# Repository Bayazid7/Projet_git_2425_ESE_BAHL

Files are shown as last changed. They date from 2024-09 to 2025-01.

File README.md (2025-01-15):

# Projet_git_2425_ESE
Projet_2024/2025
## Membres du groupes
Bayazid BELKHIR
<br>
Hedia WERHENI
<br>
Hugo DEVAUX
<br>
Aliou LY

## Introduction

Ce projet a pour objectif de développer un **robot autonome** utilisant un **microcontrôleur STM32** pour la gestion de son comportement, tout en appliquant des principes de noyaux **temps réel** pour contrôler la communication entre ses composants matériels et logiciels. Ce robot sera capable de fonctionner en deux modes :
- **Mode Chat** :
- **Mode Souris** :

Le robot est alimenté par une batterie de 7.2V et comprend des composants essentiels pour son fonctionnement tels que des moteurs, un accéléromètre, et un LIDAR.

---

## Objectifs du projet

Les principaux objectifs de ce projet sont les suivants :
1. **Conception du système à microcontrôleur STM32** : Intégrer un microcontrôleur  pour gérer le comportement du robot.
2. **Implémentation d'un noyau temps réel** : Utiliser un noyau temps réel pour garantir une gestion efficace des tâches .
3. **Contrôle des moteurs avec PWM** : Piloter deux moteurs à l'aide de drivers PWM pour contrôler la vitesse et la direction.
4. **Détection des chocs avec l'accéléromètre ADXL343** : Détecter les collisions avec d'autres robots pour ajuster les actions du robot.
5. **Détection des autres robots avec LIDAR YDLIDAR X4** : Utiliser un LIDAR pour permettre au robot de connaître la position des autres robots.


---

## Matériel utilisé

### 1. **Microcontrôleur STM32**

Le projet repose sur un **STM32** qui gère l'ensemble du système.La programmation du STM32 se fait par un SW

- **Modèle utilisé** : STM32G431CBU6
- **Fonction principale** : Gestion des moteurs, communication avec l'accéléromètre et le LIDAR, traitement des données en temps réel.
- **Peripherals** : PWM pour le contrôle des moteurs, interfaces I2C pour l'accéléromètre et UARTpour  le LIDAR et la communication avec le PC.
  image_stm32

### 2. **Alimentation et régulation de tension**

Le robot est alimenté par une batterie **NIMH 7.2V 1.3Ah**. Cette tension est ensuite convertie en différentes tensions nécessaires au bon fonctionnement des différents composants :
- **Convertisseur 3.3V BU33SD5WG-TR** pour alimenter le STM32, l'accéléromètre, et les capteurs de position des moteurs.
- **Convertisseur 5V  MP1475S** pour alimenter le LIDAR.


---

### 3. **Drivers de moteurs PWM**

Le robot est équipé de **deux moteurs DC**, chacun étant contrôlé par un driver PWM. Chaque driver reçoit des signaux PWM du STM32 pour réguler la vitesse et la direction des moteurs.

- **Modèle des drivers** : ZXBM5210-SP-13
- **Fonction principale** : Piloter les moteurs en avant ou en arrière grâce à des signaux PWM.
- **Commandes PWM** : Les signaux PWM (Forward et Reverse) contrôlent la direction des moteurs. La vitesse est ajustée en modifiant le rapport cyclique du PWM.


### 4. **Accéléromètre ADXL343**

L'accéléromètre **ADXL343** est utilisé pour détecter les chocs entre les robots. Il mesure l'accélération dans les trois axes et peut détecter des variations rapides, comme celles d'une collision.

- **Communication** : Le module utilise le protocole **I2C** pour envoyer les données d'accélération au STM32.
- **Fonction principale** : Détecter les impacts ou les vibrations et permettre une réaction rapide du robot (comme changer de direction ou ajuster son comportement).


### 5. **LIDAR YDLIDAR X2**

Le **LIDAR YDLIDAR X4** est utilisé pour scanner l'environnement autour du robot et déterminer la position des autres robots et des obstacles. 
- **Type de capteur** : **LIDAR à balayage laser**.
- **Portée** : Jusqu'à 12 mètres.
- **Communication** : **UART**  pour transmettre les données de mesure.
- **Protocole**  : Utilise une communication série avec un format de trame spécifique (en-tête 0x55AA).
- **Résolution** : Distance : 0.25 mm (valeur brute divisée par 4) et Angle : 1/64° (0.015625°)

---
# Schema de cablage



## Software

### **Drivers de Moustache**
### **1. Fichier `Moustache.c`**-contient l'implémentation du pilote pour gérer les interruptions et les tâches liées à un système utilisant des capteurs "moustaches" pour détecter des bords.
**Principales fonctions et variables :
1. **Variables principales :**
   - `cb_out1_task_handle` et `cb_out2_task_handle` : Des handles pour les tâches FreeRTOS associées aux deux GPIO.
   - `exclusive_task` : Variable pour enregistrer quelle tâche est en cours d'exécution, afin d'éviter que plusieurs tâches ne soient actives simultanément ( On a remarqué que lorsque l'une des deux moustaches détecte le bord, la deuxième va également interrompre après un petit moment, et cela est dû à la conception du robot ). 
     - `0`: Aucune tâche active.
     - `1`: La tâche `CB_OUT1_Task` est active.
     - `2`: La tâche `CB_OUT2_Task` est active.
   - `robot` : Variable globale externe, représentant l'état d'un robot. Elle est utilisée dans la fonction `Bord`.

2. **Initialisation (`Moustache_Init`):**
   - Création de deux tâches FreeRTOS :
     - `CB_OUT1_Task` pour gérer les événements associés au GPIO `CB_OUT1_Pin`.
     - `CB_OUT2_Task` pour gérer les événements associés au GPIO `CB_OUT2_Pin`.

3. **Gestion des interruptions (`Moustache_HandleInterrupt`):**
   - Cette fonction est appelée lorsqu'une interruption GPIO est détectée.
   - Vérifie si une tâche peut être exécutée (selon la valeur de `exclusive_task`).
   - Envoie une notification à la tâche correspondante (`cb_out1_task_handle` ou `cb_out2_task_handle`) en utilisant `xTaskNotifyFromISR`.

4. **Fonction `Bord` :**
   - Gère le comportement du robot en fonction de sa direction (`robot.direction`).
     - `'A'`: Le robot recule.
     - `'R'`: Le robot avance.
   - Cette fonction est appelée par les tâches pour ajuster le mouvement du robot.

5. **Tâches `CB_OUT1_Task` et `CB_OUT2_Task` :**
   - Chaque tâche attend une notification via `xTaskNotifyWait`.
   - Lorsqu'une notification est reçue :
     - Elle effectue une action définie (appel de `Bord`).
     - Réinitialise `exclusive_task` à 0 pour permettre d'autres interruptions.

#### **2. Fichier `Moustache.h`**

Ce fichier est l'en-tête associé, qui déclare les prototypes des fonctions et les dépendances nécessaires.

#### **Principales fonctionnalités :**

1. **Inclusion de bibliothèques nécessaires :**
   - `stm32g4xx_hal.h` : Bibliothèque HAL pour la famille STM32G4.
   - `gpio.h` : Bibliothèque pour gérer les GPIO.

2. **Prototypes de fonctions :**
   - `Moustache_Init(void)` : Initialisation du pilote et des tâches.
   - `Moustache_HandleInterrupt(uint16_t GPIO_Pin)` : Gestion des interruptions GPIO.

___
### **Drivers de Moteur**

### 1.Fichier 'MoteurPWM.c' 

1. **La fonction Moteur_init:** 

Est responsable de l'initialisation d'un moteur en configurant ses paramètres de base. Elle prend en entrée un pointeur vers la structure du moteur, le timer PWM et le canal associé, initialisant la direction à l'arrêt et la vitesse à zéro.

2. **Moteur_setSpeed:**
gère la vitesse du moteur avec une conversion d'échelle, transformant une vitesse d'entrée (±290) en valeur PWM (0-8500) et configurant la direction appropriée.

3. **Moteur_setDirection:**

contrôle la direction du moteur en gérant les signaux PWM complémentaires elle peut faire avancer, reculer ou arrêter le moteur en activant ou désactivant les canaux PWM appropriés.

4. **Moteur_start, Moteur_stop et Moteur_recule:**

sont des fonctions d'aide qui simplifient le contrôle du moteur en appelant Moteur_setDirection avec les paramètres appropriés.

Du côté du robot, Robot_Start initialise le mouvement en avant avec des vitesses asymétriques (120 pour la droite, 80 pour la gauche), tandis que Robot_Stop arrête les deux moteurs.Robot_Recule fait reculer le robot avec les mêmes vitesses que l'avance mais en négatif.

## 2.Fichier 'MoteurPWM.h' 

c'est un fichier d’en-tête conçu pour gérer le contrôle des moteurs d’un robot. Il définit deux structures principales :

1. **Moteur_HandleTypeDef :** utilisée pour représenter un moteur individuel, incluant ses paramètres essentiels comme le timer PWM associé (pwm_timer), le canal PWM (channel), la direction actuelle (direction) et la vitesse (vitesse).
   
2. **h_Robot :** utilisée pour représenter un robot comprenant deux moteurs (droit et gauche) et des paramètres globaux comme la vitesse linéaire, la vitesse angulaire, l’angle (theta) et le mode de fonctionnement.

pour que en peux controlé l'angle de lidar nous allons utulisé La fonction : 
xTaskCreate(robotAngle, "Init Task", 256, NULL, 2, &setangleTaskHandle)  sert à créer une tâche dans un système RTOS. Cette tâche exécute la fonction robotAngle telque: 

utilise une pile de 256 mots, et a une priorité de 2. Le nom "Init Task" est utilisé pour identifier la tâche, et le handle setangleTaskHandle permet de la contrôler ultérieurement. Cette commande initialise efficacement la tâche pour qu'elle s'exécute dans le système.

## 4 .Driver ADXL343 (`ADXL343.c`)

## Introduction

Le driver **ADXL343** permet de gérer un accéléromètre **ADXL343** dans un système embarqué en temps réel. Ce capteur mesure l'accélération sur trois axes (X, Y, Z) et est utilisé pour détecter des événements comme les chocs. Ce driver est conçu pour intégrer les fonctionnalités du capteur avec **FreeRTOS**.

### 1. **Initialisation et Configuration du Capteur**

Le driver initialise le **capteur ADXL343** en configurant les registres nécessaires pour le fonctionnement de l'accéléromètre. Cela inclut la configuration de la plage de mesures, des seuils de tapotement, et des interruptions.

- **Initialisation de l'I2C** : La fonction `ADXL343_Init()` initialise la communication I2C avec le capteur, vérifie l'identifiant du dispositif et configure les registres pour la lecture des données d'accélération.
- **Configuration des Interrups** : Le capteur est configuré pour détecter des événements sur les axes X et Y, en activant les interruptions pour ces axes.
- **Configuration du Format des Données** : Le capteur est configuré pour un mode de résolution complète avec une plage de ±16g, ce qui est adapté pour de nombreuses applications.

### 2. **Réception et Traitement des Données**

Une fois l'accéléromètre configuré, le driver permet de récupérer les données d'accélération en temps réel.
- **Traitement des Interruptions** : Le driver utilise des interruptions pour détecter des événements de tapotement (tap) sur les axes X et Y.

### 3. **Gestion des Interruptions**

- **Gestion des Interruptions Tap** : Le capteur est configuré pour activer les interruptions uniquement pour les axes X et Y, en désactivant l'axe **Z** qui peut souvent générer des interruptions indésirables.
  
### 4. **Intégration en Temps Réel** ⏱️

- **Utilisation de FreeRTOS** : Le driver fonctionne avec **FreeRTOS** pour gérer les tâches liées à la lecture des données du capteur et au traitement des événements. Une tâche dédiée `TapDetectedTask` est utilisée pour traiter les événements en temps réel.

## 5. Drivers Ylidar X2 (`lidar_X2_driver.c`)

Le code du dirver implémente la gestion d'un capteur LiDAR YLIDAR X2 dans un système embarqué temps réel. Ci-dessous, les principaux aspects du fonctionnement du LiDAR :
### Initialisation et réception des données
La fonction `lidar_init()` initialise la communication UART avec le LiDAR en mode interruption. La réception des données se fait octet par octet via la fonction `readTrame()`, qui implémente une **machine à états** pour assembler les trames complètes.
### Traitement des données
Une fois une trame complète reçue, `lidar_process()` est appelée pour extraire et traiter les données :
- `lidar_extractDataFromTrame()` décode la structure de la trame.
- `lidar_DataProcessing()` calcule la distance et l'angle pour chaque point mesuré.
- `lidar_calculatingDistance()` et `lidar_calculatingAngle()` effectuent les calculs spécifiques.

### Intégration temps réel
- Utilisation d'interruptions UART pour la réception asynchrone des données.
- Traitement des données dans une tâche FreeRTOS dédiée (`lidarTask`).
- Synchronisation avec d'autres tâches du système pour le contrôle du robot.

### Pistes d'amélioration
- Implémenter la vérification du checksum pour valider l'intégrité des données.
- Optimiser le traitement des données pour réduire la charge CPU.
- Ajouter des filtres pour améliorer la précision des mesures.
- Implémenter une gestion d'erreurs plus robuste.

## Datasheets et sourcing des composants
https://1drv.ms/x/s!AjphXEW6glNckYErezblGW1QHlP9SQ

## Démonstrations du robot en marche:

https://github.com/user-attachments/assets/f6af12cb-7911-474c-adf0-7a1f33a06a41

https://github.com/user-attachments/assets/32c66e7f-6e20-4e83-ad37-8ae89d0b7e4e

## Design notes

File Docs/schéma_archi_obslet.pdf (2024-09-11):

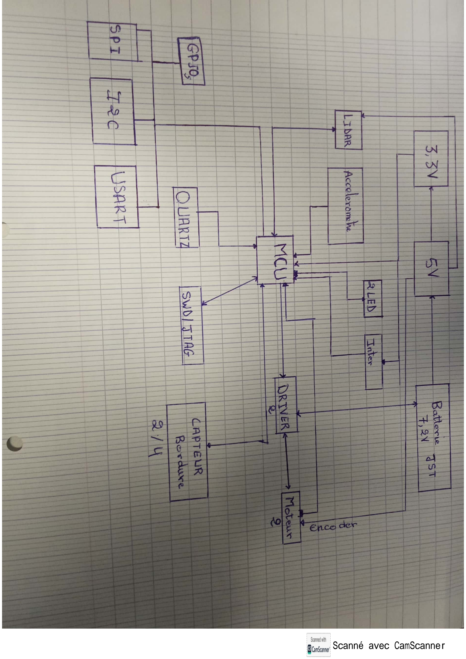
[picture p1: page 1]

Scanné avec CamScanner (https://v3.camscanner.com/user/download)

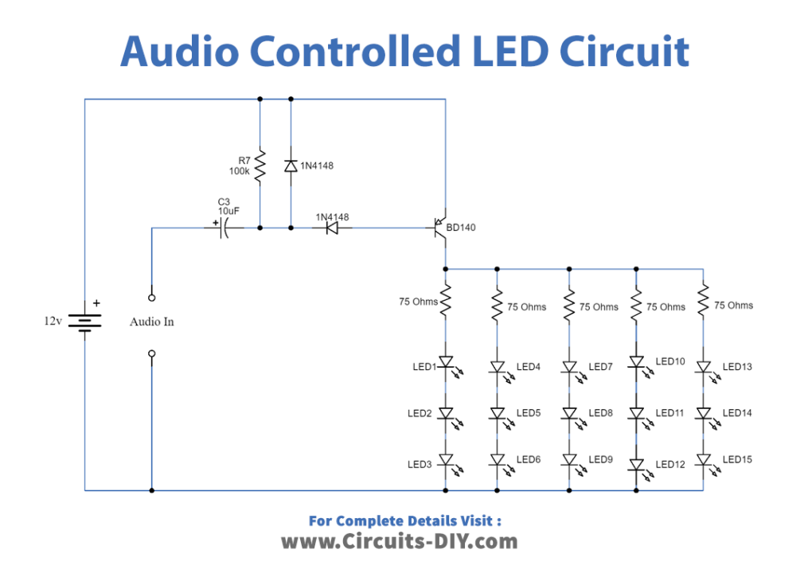
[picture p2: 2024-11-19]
Docs/LIDAR/Audio-Controlled-LED-Circuit-1015x720.png

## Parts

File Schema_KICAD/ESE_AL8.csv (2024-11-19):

Id | Référence | Empreinte | Quantité | Désignation | Fournisseur et réf
1 | R16,R1,R2,R17 | R_0402_1005Metric | 4 | 1k
2 | D3 | LED_0603_1608Metric | 1 | LED_USER2
3 | Y1 | Crystal_SMD_3225-4Pin_3.2x2.5mm | 1 | 16MHz
4 | IC1 | TSOT-23-8 | 1 | MP1475SGJ-P
5 | L1 | IND_052047_WRE | 1 | 4.7u
6 | SW1 | SW_Push_1P1T_NO_6x6mm_H9.5mm | 1 | SW_c/s
7 | C12,C16 | C_0402_1005Metric | 2 | 10p
8 | R10 | R_0402_1005Metric | 1 | 20
9 | U2 | SOT-23-5 | 1 | BUxxSD5
10 | C14,C2,C21,C20,C201,C18,C24,C19,C25,C27,C26,C17 | C_0402_1005Metric | 12 | 100n
11 | D2 | LED_0603_1608Metric | 1 | LED_USER1
12 | C5,C4,C6 | C_0402_1005Metric | 3 | 0.1u
13 | C15,C29,C11,C31,C23,C1,C10 | C_0603_1608Metric | 7 | 1u
14 | R13,R12,R3,R14,R15,R11 | R_0402_1005Metric | 6 | 680
15 | TP6,TP4,TP7,TP8,TP1,TP5,TP3,TP2 | TestPoint_Pad_D1.0mm | 8 | TestPoint
16 | R4,R5 | R_0402_1005Metric | 2 | 100K
17 | D1,D5,D6 | LED_0603_1608Metric | 3 | LED_POWER
18 | C9,C8,C3 | C_0805_2012Metric | 3 | 22u
19 | R6 | R_0603_1608Metric | 1 | 20
20 | C7 | C_0402_1005Metric | 1 | 15p
21 | J4 | JST_XH_S6B-XH-A_1x06_P2.50mm_Horizontal | 1 | Moteur1
22 | J1 | JST_XH_S4B-XH-A_1x04_P2.50mm_Horizontal | 1 | CB1
23 | J5 | JST_XH_S6B-XH-A_1x06_P2.50mm_Horizontal | 1 | Moteur2
24 | U1 | LGA-14_3x5mm_P0.8mm_LayoutBorder1x6y | 1 | ADXL343
25 | C28,C30 | C_0603_1608Metric | 2 | 10u
26 | SW2 | JST_XH_S3B-XH-A_1x03_P2.50mm_Horizontal | 1 | ON/OFF
27 | U4,U5 | Diodes_SO-8EP | 2 | ZXBM5210-SP
28 | R7 | R_0603_1608Metric | 1 | 16k
29 | L2 | C_0402_1005Metric_Pad0.74x0.62mm_HandSolder | 1 | l
30 | J8 | JST_XH_S4B-XH-A_1x04_P2.50mm_Horizontal | 1 | ECRAN
31 | D4 | LED_0603_1608Metric | 1 | LED_USER3
32 | C13 | C_0603_1608Metric | 1 | 4.7u
33 | J2 | JST_XH_S4B-XH-A_1x04_P2.50mm_Horizontal | 1 | CB2
34 | J3 | JST_XH_S8B-XH-A_1x08_P2.50mm_Horizontal | 1 | LIDAR
35 | R8 | R_0603_1608Metric | 1 | 7.68k
36 | J6 | JST_XH_S2B-XH-A_1x02_P2.50mm_Horizontal | 1 | Batterie
37 | J7 | PinHeader_2x07_P1.27mm_Vertical_SMD | 1 | Conn_ST_STDC14
38 | U3 | QFN-48-1EP_7x7mm_P0.5mm_EP5.6x5.6mm_AJ | 1 | STM32G431CBUx
39 | C22 | C_0402_1005Metric | 1 | 10n
40 | R9 | R_0603_1608Metric | 1 | 40.2k

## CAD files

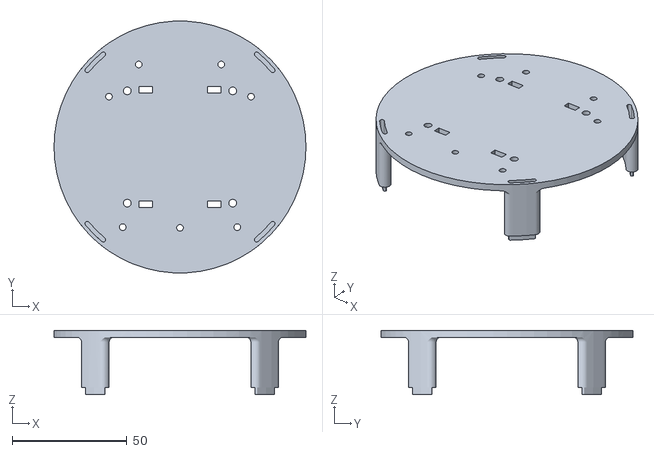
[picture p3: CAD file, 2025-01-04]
Robot_ESE_BAHL/Tower2.stl
110.0 x 109.8 x 28.0

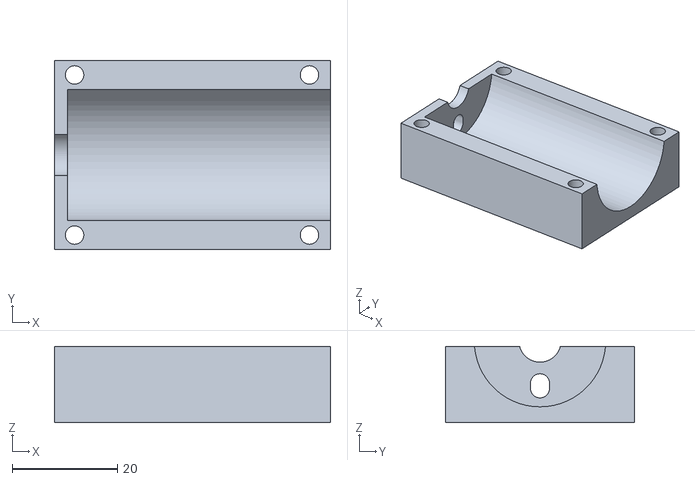
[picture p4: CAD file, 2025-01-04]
Robot_ESE_BAHL/SupportMotor2.stl
52.5 x 36.0 x 14.5

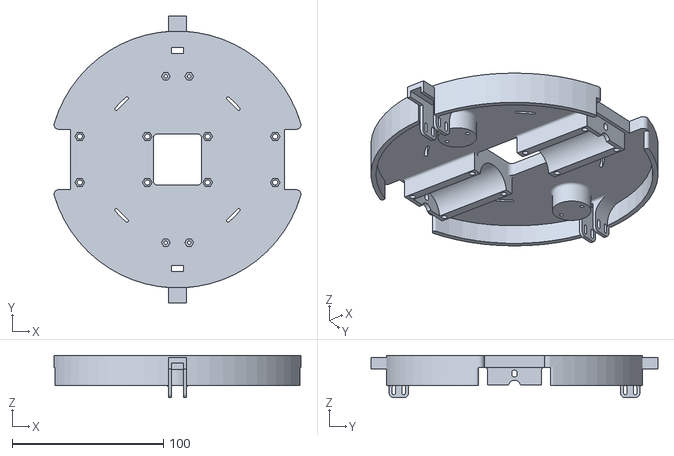
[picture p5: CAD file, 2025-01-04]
Robot_ESE_BAHL/Base (2).stl
163.4 x 190.0 x 28.0

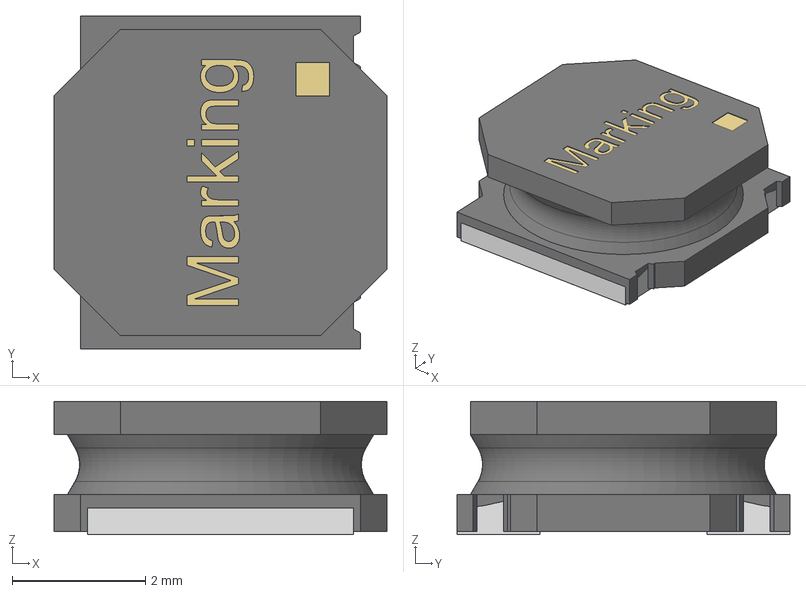
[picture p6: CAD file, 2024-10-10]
Schema_KICAD/FootPrint/Inductance/74404052010_Download_STP_WE-LQS-5020_rev1.stp
5.00 x 5.00 x 2.00 mm
housing
contact x 2
Glue

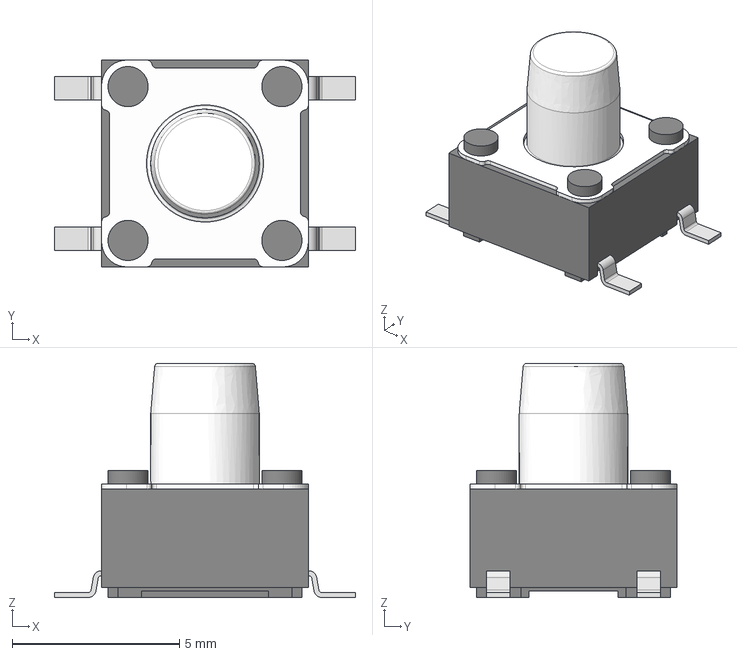
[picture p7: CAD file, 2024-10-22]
Schema_KICAD/Librairie/430182070816_Download_STP_430182070816_rev1.stp
9.00 x 6.20 x 7.00 mm

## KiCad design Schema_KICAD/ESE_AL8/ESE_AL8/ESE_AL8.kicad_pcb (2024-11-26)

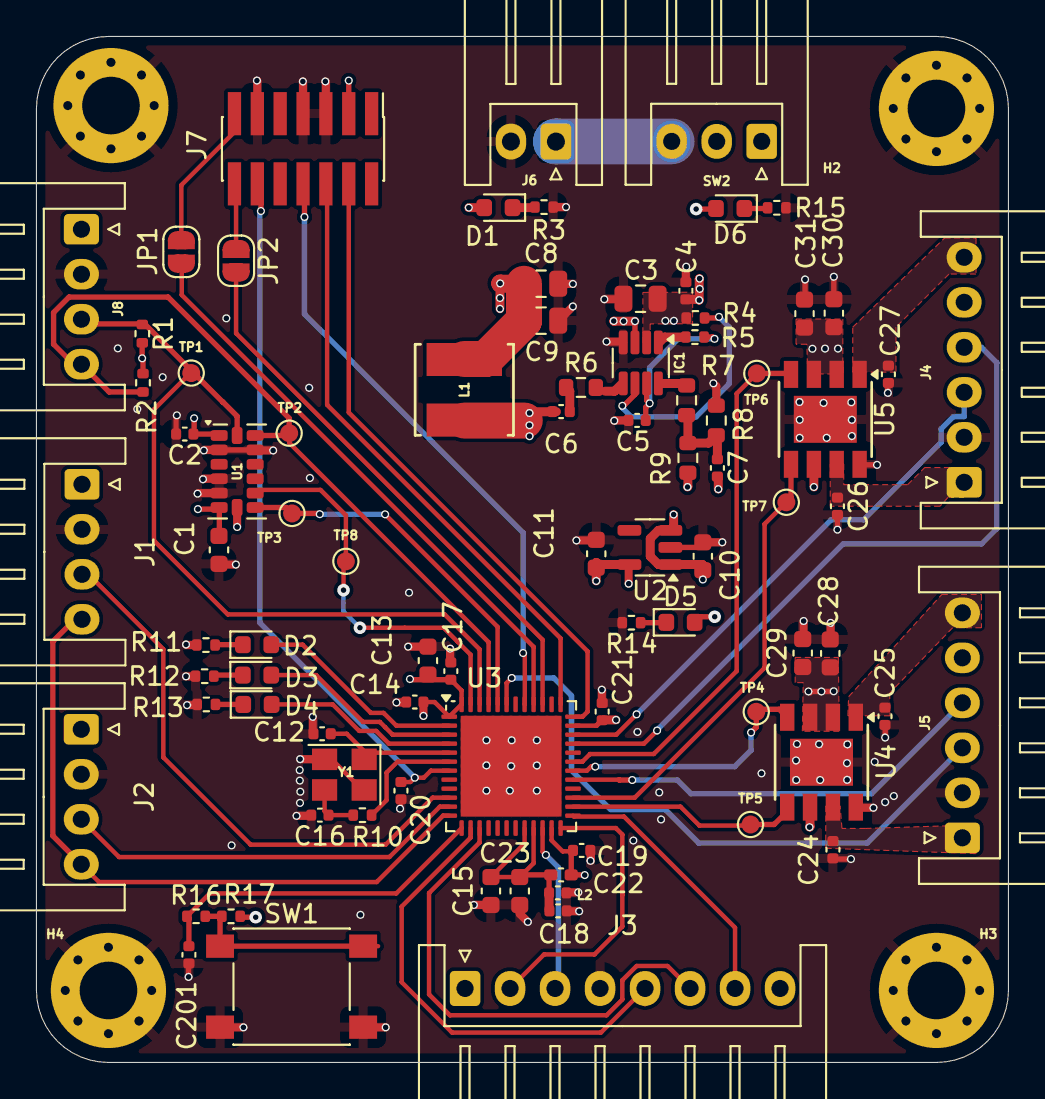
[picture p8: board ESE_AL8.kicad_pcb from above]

Board: 4 copper layers, 54.0 x 57.0 mm, 88 parts (0 on the bottom side), 60 nets.

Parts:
C1, C10, C11, C15, C23, C29, C31: 1u; C_0603_1608Metric
C2, C14, C17, C18, C19, C20, C21, C24, C25, C26, C27, C201: 100n; C_0402_1005Metric
C3, C8, C9: 22u; C_0805_2012Metric
C4, C5, C6: 0.1u; C_0402_1005Metric
C7: 15p; C_0402_1005Metric
C12, C16: 10p; C_0402_1005Metric
C13: 4.7u; C_0603_1608Metric
C22: 10n; C_0402_1005Metric
C28, C30: 10u; C_0603_1608Metric
D1, D5, D6: LED_POWER; LED_0603_1608Metric
D2: LED_USER1; LED_0603_1608Metric
D3: LED_USER2; LED_0603_1608Metric
D4: LED_USER3; LED_0603_1608Metric
H1, H2, H3, H4: MountingHole_Pad; MountingHole_3.2mm_M3_Pad_Via
IC1: MP1475SGJ-P; TSOT-23-8
J1: CB1; JST_XH_S4B-XH-A_1x04_P2.50mm_Horizontal
J2: CB2; JST_XH_S4B-XH-A_1x04_P2.50mm_Horizontal
J3: LIDAR; JST_XH_S8B-XH-A_1x08_P2.50mm_Horizontal
J4: Moteur1; JST_XH_S6B-XH-A_1x06_P2.50mm_Horizontal
J5: Moteur2; JST_XH_S6B-XH-A_1x06_P2.50mm_Horizontal
J6: Batterie; JST_XH_S2B-XH-A_1x02_P2.50mm_Horizontal
J7: Conn_ST_STDC14; PinHeader_2x07_P1.27mm_Vertical_SMD
J8: ECRAN; JST_XH_S4B-XH-A_1x04_P2.50mm_Horizontal
JP1, JP2: SolderJumper_2_Open; SolderJumper-2_P1.3mm_Open_RoundedPad1.0x1.5mm
L1: 4.7u; IND_052047_WRE
L2: l; C_0402_1005Metric_Pad0.74x0.62mm_HandSolder
R1, R2, R16, R17: 1k; R_0402_1005Metric
R3, R11, R12, R13, R14, R15: 680; R_0402_1005Metric
R4, R5: 100K; R_0402_1005Metric
R6: 20; R_0603_1608Metric
R7: 16k; R_0603_1608Metric
R8: 7.68k; R_0603_1608Metric
R9: 40.2k; R_0603_1608Metric
R10: 20; R_0402_1005Metric
SW1: SW_c/s; SW_Push_1P1T_NO_6x6mm_H9.5mm
SW2: ON/OFF; JST_XH_S3B-XH-A_1x03_P2.50mm_Horizontal
TP1, TP2, TP3, TP4, TP5, TP6, TP7, TP8: TestPoint; TestPoint_Pad_D1.0mm
U1: ADXL343; LGA-14_3x5mm_P0.8mm_LayoutBorder1x6y
U2: BUxxSD5; SOT-23-5
U3: STM32G431CBUx; QFN-48-1EP_7x7mm_P0.5mm_EP5.6x5.6mm_AJ
U4, U5: ZXBM5210-SP; Diodes_SO-8EP
Y1: 16MHz; Crystal_SMD_3225-4Pin_3.2x2.5mm

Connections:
+3.3V: C1.1, C2.1, C11.1, C13.1, C14.1, C17.1, C19.1, C21.1, D1.2 (A), J1.1, J2.1, J4.5, J5.5, J7.3 (VCC), J8.1, L2.2, R1.2, R2.2, R17.1, U1.1 (Vdd_I/O), U1.6 (Vs), U1.7 (~CS), U2.5 (VOUT), U3.1 (VBAT), U3.23 (VDD), U3.35 (VDD), U3.48 (VDD)
+3.3VA: C15.1, C18.1, C22.1, C23.1, L2.1, U3.20 (VREF+), U3.21 (VDDA)
+5V: C7.2, C8.1, C9.1, C10.1, D5.2 (A), J3.1, L1.2, R9.2, U2.1 (VIN), U2.3 (STBY)
+7.2V: J6.1, SW2.3 (A)
+BATT: C3.1, C4.1, C28.1, C29.1, C30.2, C31.2, D6.2 (A), IC1.2 (IN), R4.1, SW2.2 (B), U4.2 (VM), U4.3 (VDD), U4.6 (VREF), U5.2 (VM), U5.3 (VDD), U5.6 (VREF)
/Actionneur/FWD1: TP6.1, U3.31 (PA9), U5.4 (FWD)
/Actionneur/FWD2: TP4.1, U3.30 (PA8), U4.4 (FWD)
/Actionneur/MOTEUR1+: C27.2, J4.6, U5.1 (OUT1)
/Actionneur/MOTEUR1-: C26.1, J4.1, U5.7 (OUT2)
/Actionneur/MOTEUR2+: C25.2, J5.6, U4.1 (OUT1)
/Actionneur/MOTEUR2-: C24.1, J5.1, U4.7 (OUT2)
/Actionneur/REV1: TP7.1, U3.27 (PB14), U5.5 (REV)
/Actionneur/REV2: TP5.1, U3.26 (PB13), U4.5 (REV)
/Actionneur/SCL: J8.3, R1.1, TP1.1, U1.14 (SCL/SCLK), U3.46 (PB8)
/Actionneur/SDA: J8.4, R2.1, TP2.1, U1.13 (SDA/SDI/SDIO), U3.45 (PB7)
/Alimentation/bst: IC1.5 (BST), R6.1
/Alimentation/en/sync: IC1.6 (EN/SYNC), R4.2
/Alimentation/fb: IC1.8 (FB), R7.1
/Alimentation/led_power: D1.1 (K), R3.1
/Alimentation/led_power5: D5.1 (K), R14.1
/Alimentation/led_powerBATT: D6.1 (K), R15.1
/Alimentation/pg: IC1.1 (PG), R5.2
/Alimentation/sw: C6.2, IC1.3 (SW), L1.1
/Alimentation/vcc: C5.1, IC1.7 (VCC), R5.1
/SENSORS/CB_IN: J1.4, J2.4, U3.12 (PA4)
/SENSORS/CB_OUT1: J1.3, U3.10 (PA2)
/SENSORS/CB_OUT2: J2.3, U3.11 (PA3)
/SENSORS/CHAT/SOURIS: C201.1, R16.1, U3.13 (PA5)
/SENSORS/DEV_EN_LIDAR: J3.6, U3.15 (PA7)
/SENSORS/INT1_ACCELERO: TP3.1, U1.8 (INT1), U3.44 (PB6)
/SENSORS/INT2_ACCELERO: TP8.1, U1.9 (INT2), U3.47 (PB9)
/SENSORS/M_EN_LIDAR: J3.7, U3.25 (PB12)
/SENSORS/M_SCTR_LIDAR: J3.5, U3.14 (PA6)
/SENSORS/PHASE_A1: J4.3, U3.34 (PA12)
/SENSORS/PHASE_A2: J5.3, U3.43 (PB5)
/SENSORS/PHASE_B1: J4.4, U3.33 (PA11)
/SENSORS/PHASE_B2: J5.4, U3.29 (PC6)
/SENSORS/RX_LIDAR: J3.3, U3.22 (PB10)
/SENSORS/TX_LIDAR: J3.2, U3.24 (PB11)
/STM32/LED1: D2.1 (K), R11.1
/STM32/LED2: D3.1 (K), R12.1
/STM32/LED3: D4.1 (K), R13.1
GND: C1.2, C2.2, C3.2, C4.2, C5.2, C8.2, C9.2, C10.2, C11.2, C12.1, C13.2, C14.2, C15.2, C16.2, C17.2, C18.2, C19.2, C20.2, C21.2, C22.2, C23.2, C24.2, C25.1, C26.2, C27.1, C28.2, C29.2, C30.1, C31.1, C201.2, H1.1, H2.1, H3.1, H4.1, IC1.4 (GND), J1.2, J2.2, J3.4, J4.2, J5.2, J6.2, J7.5 (GND), J7.7 (GND), J7.11 (GNDDetect), J8.2, R3.2, R8.2, R11.2, R12.2, R13.2, R14.2, R15.2, SW1.2, U1.2 (GND), U1.4 (GND), U1.5 (GND), U1.12 (SDO/ADDR), U2.2 (GND), U3.49 (VSS), U4.8 (GND), U4.9 (GND), U5.8 (GND), U5.9 (GND), Y1.2, Y1.4
LD1: D2.2 (A), U3.2 (PC13)
LD2: D3.2 (A), U3.3 (PC14)
LD3: D4.2 (A), U3.4 (PC15)
NRST: C20.1, J7.12 (~RST), U3.7 (PG10)
unnamed: C6.1, R6.2
unnamed: C7.1, R7.2, R8.1, R9.1
unnamed: C16.1, R10.1, Y1.3
unnamed: J7.13 (VCP_RX), JP1.1 (A)
unnamed: J7.14 (VCP_TX), JP2.1 (A)
unnamed: R16.2, R17.2, SW1.1
OSC_IN: C12.2, U3.5 (PF0), Y1.1
OSC_OUT: R10.2, U3.6 (PF1)
RX_SWD: JP1.2 (B), U3.40 (PC11)
SWCLK: J7.6 (JCLK/SWCLK), U3.37 (PA14)
SWDIO: J7.4 (JTMS/SWDIO), U3.36 (PA13)
SWO: J7.8 (JTDO/SWO), U3.41 (PB3)
TX_SWD: JP2.2 (B), U3.39 (PC10)

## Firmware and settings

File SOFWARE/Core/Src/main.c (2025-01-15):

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
/* Includes ------------------------------------------------------------------*/
#include "main.h"
#include "cmsis_os.h"
#include "i2c.h"
#include "tim.h"
#include "usart.h"
#include "gpio.h"

/* USER CODE BEGIN Includes */
#include <stdio.h>
#include "tab.h"
#include "lidar_X2_driver.h"
#include "MoteurPWM.h"
#include "Moustache.h"
#include "ADXL343.h"
/* USER CODE END Includes */


/* USER CODE BEGIN PV */

extern uint8_t sendTab[TABLE_SIZE];
extern uint8_t flagDMA;
extern uint8_t rxByte;
extern float lidar_point[SIZE_POINT] ;
uint8_t flag = 0;

// FreeRTOS Task Handles
TaskHandle_t initTaskHandle = NULL;
TaskHandle_t lidarTaskHandle = NULL;
TaskHandle_t ledBlinkTaskHandle = NULL;
TaskHandle_t h_task_bord = NULL;
static TaskHandle_t TapDetected_task = NULL;
TaskHandle_t modeTaskHandle = NULL;
TaskHandle_t setangleTaskHandle = NULL;

// Robot and peripheral structures
Moteur_HandleTypeDef moteur_droit;
Moteur_HandleTypeDef moteur_gauche;
h_Robot robot;
float angle;
ADXL343_InstanceDef_t ADXL343;
/* USER CODE END PV */

void SystemClock_Config(void);
void MX_FREERTOS_Init(void);
/* USER CODE BEGIN PFP */
int __io_putchar(int chr);
void lidarTask(void *pvParameters);
void ledBlinkTask(void *pvParameters);
void task_angle(void *unused);
void task_Bord(void *unused);
void TapDetected(void *param);
void modeChange(void *param);
void initTask(void *pvParameters);
void robotAngle(void * param);
/* USER CODE END PFP */

/**
 * @brief  The application entry point.
 * @retval int
 */
int main(void)
{

	/* MCU Configuration--------------------------------------------------------*/

	/* Reset of all peripherals, Initializes the Flash interface and the Systick. */
	HAL_Init();

	/* Configure the system clock */
	SystemClock_Config();

	/* Initialize all configured peripherals */
	MX_GPIO_Init();
	MX_TIM1_Init();
	MX_TIM16_Init();
	MX_UART4_Init();
	MX_USART3_UART_Init();
	MX_I2C1_Init();
	MX_TIM2_Init();
	/* USER CODE BEGIN 2 */
	// Peripheral Initialization

	Moteur_init(&moteur_droit, &htim1, TIM_CHANNEL_1);
	Moteur_init(&moteur_gauche, &htim1, TIM_CHANNEL_2);
	Robot_Init(&robot, &moteur_droit, &moteur_gauche);
	Robot_Start(&robot);
	Moustache_Init();
	ADXL343_Init(&ADXL343, &hi2c1);
	HAL_TIM_Base_Start_IT(&htim2) ;
	//Create FreeRTOS tasks
	xTaskCreate(lidarTask, "Lidar Task", 512, NULL, 2, &lidarTaskHandle);
	xTaskCreate(ledBlinkTask, "LED Blink Task", 256, NULL,2, &ledBlinkTaskHandle);
	xTaskCreate(modeChange, "mode", 128, NULL, 5, &modeTaskHandle);
	xTaskCreate(TapDetected, "TapDetected", 128, NULL, 5, &TapDetected_task);
	xTaskCreate(initTask, "Init Task", 256, NULL, 7, &initTaskHandle);
	xTaskCreate(robotAngle, "Init Task", 256, NULL, 2, &setangleTaskHandle) ;

	//
	/* USER CODE END 2 */

	/* Call init function for freertos objects (in cmsis_os2.c) */
	MX_FREERTOS_Init();

	/* Start scheduler */
	osKernelStart();

	/* We should never get here as control is now taken by the scheduler */

	/* Infinite loop */
	/* USER CODE BEGIN WHILE */

	while (1)
	{
		HAL_GPIO_TogglePin(LED1_GPIO_Port, LED1_Pin);
		HAL_GPIO_TogglePin(LED2_GPIO_Port, LED2_Pin);
		HAL_GPIO_TogglePin(LED3_GPIO_Port, LED3_Pin);
		HAL_Delay(500);
		//vTaskDelay(pdMS_TO_TICKS(500));
		//lidar_scan_loop();
		/*if(flag == 1){
			for(int i=0 ; i<POINT_BUFF_SIZE ;i++)
			{
				printf("le point %d a angle %f et diastance %f \r\n",i,lidar.point[i].Angle,lidar.point[i].Distance);
				printf("FSA = %d,LSA=%d , LSN=%d , ind=%d \r\n",lidar.processing.LSA,lidar.processing.LSA,lidar.processing.LSN,lidar.processing.idx);
			}
			flag = 0 ;
		}*/

		/* USER CODE END WHILE */

		/* USER CODE BEGIN 3 */
	}
	/* USER CODE END 3 */
}

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
/* USER CODE BEGIN 4 */

//Lidar Task
void initTask (void *pvParameters)
{
	lidar_init();
	vTaskDelete(NULL);
}

void lidarTask(void *pvParameters)
{
	for(;;)
	{
		if (ulTaskNotifyTake(pdTRUE, portMAX_DELAY) == pdTRUE)
		{
			lidar_process();
		}
	}
}
// Robot orientation task
void robotAngle(void * param)
{ float angle = 0 ;
for(;;)
{

	if (ulTaskNotifyTake(pdTRUE, portMAX_DELAY) == pdTRUE)
	{
		angle = angle +90  ;
		//float distance = lidar_point[0] ;
		//for(int i=1 ; i<SIZE_POINT ; i++)
		//{
		//	if((lidar_point[i]>distance)&&(lidar_point[i]!=0))
		//{
		//	distance = lidar_point[i] ;
		//	angle = i ;
		//}
		//}
		printf("l'angle = %f \n",angle);
		Robot_setAngle(&robot, angle);
	}
}
}
//LED Blink Task
void ledBlinkTask(void *pvParameters) {
	for (;;) {
		if(robot.mode==0)
		{
			HAL_GPIO_TogglePin(LED1_GPIO_Port, LED1_Pin);
			//HAL_GPIO_TogglePin(LED2_GPIO_Port, LED2_Pin);
		}
		else if(robot.mode==1)
		{
			HAL_GPIO_TogglePin(LED3_GPIO_Port, LED3_Pin);
		}
		vTaskDelay(pdMS_TO_TICKS(500));
	}
}

//mode change Task
void modeChange(void *param) {
	uint32_t ulNotificationValue;

	for(;;) {
		ulNotificationValue = ulTaskNotifyTake(pdTRUE, portMAX_DELAY);
		if (ulNotificationValue != 0){
			if(robot.mode == 0)
			{
				robot.mode = 1;
			}
			else
			{
				robot.mode = 0;
			}
		}
	}
}
//Tap Detection Task
void TapDetected(void *param) {
	uint32_t ulNotificationValue;

	for(;;) {
		ulNotificationValue = ulTaskNotifyTake(pdTRUE, portMAX_DELAY);
		if (ulNotificationValue != 0) {
			uint8_t buf;
			HAL_I2C_Mem_Read(&hi2c1, ADXL343_ADDRESS, ADXL343_REG_INT_SOURCE,
					I2C_MEMADD_SIZE_8BIT, &buf, 1, HAL_MAX_DELAY);
			Robot_Stop(&robot);
			if(robot.mode == 0)
			{
				robot.mode = 1;
			}
			else
			{
				robot.mode = 0;
			}
		}
	}
}

//Fonctions CALLBACK

void HAL_GPIO_EXTI_Callback(uint16_t GPIO_Pin)
{
	if(GPIO_Pin==CHAT_SOURIS_Pin)
	{
		BaseType_t xHigherPriorityTaskWoken = pdFALSE;
		vTaskNotifyGiveFromISR(modeTaskHandle, &xHigherPriorityTaskWoken);
		portYIELD_FROM_ISR(xHigherPriorityTaskWoken);
	}
	else if(GPIO_Pin==INT2_Pin)
	{
		BaseType_t xHigherPriorityTaskWoken = pdFALSE;
		vTaskNotifyGiveFromISR(TapDetected_task, &xHigherPriorityTaskWoken);
		portYIELD_FROM_ISR(xHigherPriorityTaskWoken);
	}

	Moustache_HandleInterrupt(GPIO_Pin);
}
void HAL_UART_RxCpltCallback(UART_HandleTypeDef *huart)
{
	if (huart->Instance == USART3)
	{
		if(readTrame(&rxByte))
		{
			BaseType_t xHigherPriorityTaskWoken = pdFALSE;
			vTaskNotifyGiveFromISR(lidarTaskHandle, &xHigherPriorityTaskWoken);
			portYIELD_FROM_ISR(xHigherPriorityTaskWoken);
		}
		HAL_UART_Receive_IT(&huart3, &rxByte, 1);
	}
}


int __io_putchar(int chr)
{
	HAL_UART_Transmit(&huart4, (uint8_t *)&chr, 1, HAL_MAX_DELAY);
	return chr;
}
/* USER CODE END 4 */

/**
 * @brief  Period elapsed callback in non blocking mode
 * @note   This function is called  when TIM6 interrupt took place, inside
 * HAL_TIM_IRQHandler(). It makes a direct call to HAL_IncTick() to increment
 * a global variable "uwTick" used as application time base.
 * @param  htim : TIM handle
 * @retval None
 */
void HAL_TIM_PeriodElapsedCallback(TIM_HandleTypeDef *htim)
{
	if (htim->Instance == TIM6) {
		HAL_IncTick();
	}
	/* USER CODE BEGIN Callback 1 */
	if (htim->Instance == TIM2) {
		BaseType_t xHigherPriorityTaskWoken = pdFALSE;
		vTaskNotifyGiveFromISR(setangleTaskHandle, &xHigherPriorityTaskWoken);
		portYIELD_FROM_ISR(xHigherPriorityTaskWoken);
	}
	/* USER CODE END Callback 1 */
}

/**
 * @brief  This function is executed in case of error occurrence.
 * @retval None
 */
void Error_Handler(void)
{
	/* USER CODE BEGIN Error_Handler_Debug */
	/* User can add his own implementation to report the HAL error return state */
	__disable_irq();
	while (1)
	{
	}
	/* USER CODE END Error_Handler_Debug */
}

#ifdef  USE_FULL_ASSERT
/**
 * @brief  Reports the name of the source file and the source line number
 *         where the assert_param error has occurred.
 * @param  file: pointer to the source file name
 * @param  line: assert_param error line source number
 * @retval None
 */
void assert_failed(uint8_t *file, uint32_t line)
{
	/* USER CODE BEGIN 6 */
	/* User can add his own implementation to report the file name and line number,
     ex: printf("Wrong parameters value: file %s on line %d\r\n", file, line) */
	/* USER CODE END 6 */
}
#endif /* USE_FULL_ASSERT */

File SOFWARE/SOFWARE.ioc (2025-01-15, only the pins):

Mcu.UserName=STM32G431CBUx
PA13.GPIO_Label=SWDIO
PA13.Signal=SYS_JTMS-SWDIO
PA14.GPIO_Label=SWCLK
PA14.Signal=SYS_JTCK-SWCLK
PA2.GPIO_Label=CB_OUT1
PA2.Signal=GPXTI2
PA3.GPIO_Label=CB_OUT2
PA3.Signal=GPXTI3
PA4.GPIO_Label=CB_IN
PA4.Signal=GPIO_Output
PA5.GPIO_Label=CHAT/SOURIS
PA5.Signal=GPXTI5
PA6.GPIO_Label=M_SCTR_LIDAR
PA6.Signal=S_TIM16_CH1
PA7.GPIO_Label=DEV_EN_LIDAR
PA7.Signal=GPIO_Output
PA8.Signal=S_TIM1_CH1
PA9.Signal=S_TIM1_CH2
PB10.GPIO_Label=LIDAR_RX
PB10.Signal=USART3_TX
PB11.GPIO_Label=LIDAR_TX
PB11.Signal=USART3_RX
PB12.GPIO_Label=M_EN_LIDAR
PB12.Signal=GPIO_Output
PB13.Signal=TIM1_CH1N
PB14.Signal=TIM1_CH2N
PB3.GPIO_Label=SWO
PB3.Signal=SYS_JTDO-SWO
PB7.Signal=I2C1_SDA
PB8-BOOT0.Signal=I2C1_SCL
PB9.GPIO_Label=INT2
PB9.Signal=GPXTI9
PC10.GPIO_Label=TX_SWD
PC10.Signal=UART4_TX
PC11.GPIO_Label=RX_SWD
PC11.Signal=UART4_RX
PC13.GPIO_Label=LED1
PC13.Signal=GPIO_Output
PC14-OSC32_IN.GPIO_Label=LED2
PC14-OSC32_IN.Signal=GPIO_Output
PC15-OSC32_OUT.GPIO_Label=LED3
PC15-OSC32_OUT.Signal=GPIO_Output
PF0-OSC_IN.Signal=RCC_OSC_IN
PF1-OSC_OUT.Signal=RCC_OSC_OUT

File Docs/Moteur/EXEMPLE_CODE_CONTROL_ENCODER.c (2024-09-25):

// Prérequis savoir utiliser un timer 
#include <TimerOne.h> // Pour le timer


// Prérequis savoir utiliser les define
// Partie à modifier pour indiquer en define quel pin est branché où A et B à brancher sur 2 et 4
#define ENCODEURA 2
#define ENCODEURB 4


// prérequis : volatile => pour toute variable qui sera utilise dans les interruptions 

volatile int count =0; // comptage de tick d'encoder  qui sera incrémenté sur interruption " On change " sur l'interruption matériel 0 qui se fait sur le pin 2
volatile double speed =0; // vitesse du moteur 
volatile byte laststate =0;  // etat précédent de l'encodeur 


// Contrôle PWM simple
#define A 5 // Contrôle vitesse moteur 1
#define B 6 //controle direction moteur 1

void stop() //Stop
{
digitalWrite(A,LOW);
digitalWrite(B,LOW);
}

void advance(char a) // En avant
{
analogWrite (A,a); // Contrôle de vitesse en PWM
digitalWrite(B,HIGH);
}

void back_off (char a) // En arrière
{
analogWrite (A,a);
digitalWrite(B,LOW);
}

void setup()
{
// on initialise les entrées et sorties
 pinMode(ENCODEURA, INPUT_PULLUP);
 pinMode(ENCODEURB, INPUT_PULLUP);
 
pinMode(A, OUTPUT);
pinMode(B, OUTPUT);
 
attachInterrupt(0,counter, CHANGE); // on crée l'interruption sur changement sur la pin 2 => interruption 0, la routine counter va se faire toute seule sans l'appeler à chaque changement d'état sur le pin 2

Timer1.initialize(100000); // On défini le timeur : 100000 microseconds ( 0.1 sec - or 10Hz )
Timer1.attachInterrupt( timerIsr ); // attach the service routine here la fonction timerIsr est une routine qui va se faire automatiquement 10* par secondes sans l'appeler

Serial.begin(9600); // Définit vitesse de transmission série
Serial.println("Execution du controle par clavier");
}

void loop()
{
if(Serial.available()){
char val = Serial.read(); //récupération des caractères sur le
if(val != -1)             //port série
{
switch(val)
{
case 'z':// En avant si touche "z"
advance (255-255); // en avant vitesse max
                  // le driver fonctionne à l'état bas en marche avant
break;
case 's':// En arrière si touche "s"
back_off (255); // en arrière vitesse max
              // le driver fonctionne à l'état haut en marche arrière
break;
case 'x': // arrêt si touche "x"
stop();
break;
}
}
else stop();
}

Serial.println("speed");             
Serial.println(speed); 
}


// Encoder counter 0

void counter()
{
  byte state=PIND;
  
  state|=B11101011;  // mask pour ne regarder que les changements sur 2 et 4 
  // Modifier le MASK  B01111011 par BXXXXXXXX mettre des 0 là où sont les pins utilisés par l'encodeur
  if( state!=laststate)
  {
    (((state&(1<<ENCODEURA))>>ENCODEURA)^((state&(1<<ENCODEURB))>>ENCODEURB))?count--:count++;
    laststate=state;
  }
}


// Timer event to calculate speed from counters

void timerIsr()
{
    speed=count; // on a le nombre de tick ( signé ) par unité de temps  = vitesse
    count=0; // On remet le compteur de tick à 0 
}

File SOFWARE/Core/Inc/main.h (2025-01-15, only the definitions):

#define LED1_Pin GPIO_PIN_13
#define LED1_GPIO_Port GPIOC
#define LED2_Pin GPIO_PIN_14
#define LED2_GPIO_Port GPIOC
#define LED3_Pin GPIO_PIN_15
#define LED3_GPIO_Port GPIOC
#define CB_OUT1_Pin GPIO_PIN_2
#define CB_OUT1_GPIO_Port GPIOA
#define CB_OUT1_EXTI_IRQn EXTI2_IRQn
#define CB_OUT2_Pin GPIO_PIN_3
#define CB_OUT2_GPIO_Port GPIOA
#define CB_OUT2_EXTI_IRQn EXTI3_IRQn
#define CB_IN_Pin GPIO_PIN_4
#define CB_IN_GPIO_Port GPIOA
#define CHAT_SOURIS_Pin GPIO_PIN_5
#define CHAT_SOURIS_GPIO_Port GPIOA
#define CHAT_SOURIS_EXTI_IRQn EXTI9_5_IRQn
#define M_SCTR_LIDAR_Pin GPIO_PIN_6
#define M_SCTR_LIDAR_GPIO_Port GPIOA
#define DEV_EN_LIDAR_Pin GPIO_PIN_7
#define DEV_EN_LIDAR_GPIO_Port GPIOA
#define LIDAR_RX_Pin GPIO_PIN_10
#define LIDAR_RX_GPIO_Port GPIOB
#define LIDAR_TX_Pin GPIO_PIN_11
#define LIDAR_TX_GPIO_Port GPIOB
#define M_EN_LIDAR_Pin GPIO_PIN_12
#define M_EN_LIDAR_GPIO_Port GPIOB
#define SWDIO_Pin GPIO_PIN_13
#define SWDIO_GPIO_Port GPIOA
#define SWCLK_Pin GPIO_PIN_14
#define SWCLK_GPIO_Port GPIOA
#define TX_SWD_Pin GPIO_PIN_10
#define TX_SWD_GPIO_Port GPIOC
#define RX_SWD_Pin GPIO_PIN_11
#define RX_SWD_GPIO_Port GPIOC
#define SWO_Pin GPIO_PIN_3
#define SWO_GPIO_Port GPIOB
#define INT2_Pin GPIO_PIN_9
#define INT2_GPIO_Port GPIOB
#define INT2_EXTI_IRQn EXTI9_5_IRQn

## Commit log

2024-09-11 Pour le schema_archi
    [ESE_AL8.kicad_pcb, ESE_AL8.kicad_sch]
2024-09-18 commit 18/09/202
    [ESE_AL8.kicad_pcb, ESE_AL8.kicad_sch, ZXBM5210-S-13.stp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]
2024-09-18 commit pour 18/09
    [ESE_AL8.kicad_sch, alimentation.kicad_sch, sensors.kicad_sch]
2024-09-18 commit 18/09/24 18:10
    [ESE_AL8.kicad_pcb, ESE_AL8.kicad_sch]
2024-09-25 LE 25 /09/2024 10:31
    [ESE_AL8-B_Cu.gbr, ESE_AL8-B_Mask.gbr, ESE_AL8-B_Paste.gbr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]
2024-09-25 commit 3
    [ESE_AL8.kicad_pcb]
2024-09-25 commit AL08_1
    [ESE_AL8.kicad_sch]
2024-10-01 commit du code et kicad modifié
    [Actionneur.kicad_sch, ESE_AL8.kicad_pcb, ESE_AL8.kicad_sch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]
2024-10-01 commit pour le schema
    [Actionneur.kicad_sch, ESE_AL8.kicad_sch, alimentation.kicad_sch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]
2024-10-01 kicad updated
    [Actionneur.kicad_sch, ESE_AL8.kicad_pcb, ESE_AL8.kicad_sch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]
2024-10-01 kicad delete
    [Actionneur.kicad_sch, ESE_AL8.kicad_pcb, ESE_AL8.kicad_sch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]
2024-10-10 Routage aprés correction
    [74404052010_Download_STP_WE-LQS-5020_rev1.stp, Actionneur.kicad_sch, ESE_AL8.kicad_pcb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]
2024-10-22 Commit midif pcb 2020
    [ESE_AL8.kicad_pcb, alimentation.kicad_sch, sensors.kicad_sch]
2024-10-22 Commit midif pcb 2207
    [ESE_AL8-B_Cu.gbr, ESE_AL8-B_Mask.gbr, ESE_AL8-B_Paste.gbr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]
2024-10-23 Commit midif pcb 23/10 0816
    [ESE_AL8.kicad_pcb, STM32.kicad_sch]
2024-10-23 Commit midif pcb 23/10 0914
    [ESE_AL8-B_Cu.gbr, ESE_AL8-B_Mask.gbr, ESE_AL8-B_Paste.gbr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]
2024-10-23 Commit midif pcb 23/10 0916
2024-10-23 Commit last modif 23/10/24 11:05
    [ESE_AL8-B_Cu.gbr, ESE_AL8-B_Mask.gbr, ESE_AL8-B_Paste.gbr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]
2024-10-23 Commit last modif 23/10/24 11:29
    [ESE_AL8-B_Cu.gbr, ESE_AL8-B_Mask.gbr, ESE_AL8-B_Paste.gbr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]
2024-11-19 le bon ioc
    [ESE_AL8.csv, ESE_AL8.kicad_pcb, alimentation.kicad_sch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]
2024-11-26 push 26/11
    [ESE_AL8.kicad_pcb, SOFWARE Debug.cfg, STM32.kicad_sch]
2025-01-04 commit merge 1
    [Base (2).stl, SupportMotor1.stl, SupportMotor2.stl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]
2025-01-09 new version
    [Actionneur.kicad_sch]

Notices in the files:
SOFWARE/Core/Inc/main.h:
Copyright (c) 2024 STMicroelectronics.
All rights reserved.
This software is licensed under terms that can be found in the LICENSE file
